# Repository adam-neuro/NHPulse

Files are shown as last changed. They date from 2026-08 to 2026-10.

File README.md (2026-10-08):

# NHPulse

NHPulse is a MATLAB research workflow for individualized non-human-primate
EEG/tES cap design. It extends the ROAST electric-field modeling toolbox with
utilities for synthetic/reviewer examples, subject-specific scalp and implant
registration, capMaker-style layout design, sparse tES targeting, EEG
interleaving, and PLA/TPE STL generation.

The current release is a working research-software alpha. Its thin application
shell opens manifest-backed projects and launches specialized GUIs, while the
reviewer walkthrough remains script-based so every file, setting, and
intermediate product is inspectable.

## Reviewer Quick Start

Open MATLAB from the repository root and run:

```matlab
setNHPulsePath;
P = nhpulseConfigureLocalPaths('profile', 'syntheticMwe');
report = nhpulseCheckDependencies();
```

If the report lists missing dependencies, install those packages before running
the smoke test. A convenient local drop zone is `lib/` inside this repository;
for example, an SPM download may be left as `lib/spm`, `lib/spm12`, or
`lib/spm12-main`. `setNHPulsePath` searches `lib/` for diagnostic dependency
functions rather than requiring exact folder names. You can also point NHPulse
to dependencies installed elsewhere with:

```matlab
P = nhpulseConfigureLocalPaths('profile', 'syntheticMwe', 'useGui', true);
```

or by editing the generated `local.paths.json` file directly. Important fields
include `spmPath`, `iso2meshPath`, `cvxPath`, `getdpExecutable`, and
`gmshExecutable`; see [Configuration](docs/configuration.md) and
[Dependencies And Third-Party Notices](DEPENDENCIES.md) for details.

On macOS, freshly downloaded MATLAB dependencies may have quarantined MEX files.
After configuring paths, clear the quarantine attribute and restart MATLAB:

```matlab
nhpulseClearMacQuarantine({'spm', 'cvx', 'iso2mesh', 'getdp'})
```

If you are only fixing SPM, `nhpulseClearMacQuarantine('spm')` is enough. You
can also pass a direct folder path such as
`nhpulseClearMacQuarantine('/Users/you/Documents/MATLAB/NHPulse/lib/spm12-main')`.
For real ROAST/GetDP solves, also clear the folder containing the GetDP
executable if macOS reports that it cannot be verified.

After the dependency report says the synthetic smoke test is likely runnable,
run:

```matlab
setNHPulsePath;
P = nhpulseConfigureLocalPaths('profile', 'syntheticMwe');
report = nhpulseCheckDependencies();
smokeOut = nhpulseRunSyntheticSmokeTest('force', true, 'showFigures', true);
```

The smoke test records a small manifest-backed run that can immediately be
opened with `nhpulseApp(P.outputRoot)`. Older output folders are shown as
**Unregistered outputs** and can be adopted without moving their files.

Then open [exampleWalkthrough.m](exampleWalkthrough.m) and run the cells in
order. The default preset uses interactive GUI steps and dummy lead fields so a
reviewer can exercise the full cap-manufacturing path without waiting for long
finite-element solves. To run the same walkthrough without interaction:

```matlab
cfg = nhpulseExampleConfig('syntheticFast');
```

To exercise real ROAST/GetDP lead-field generation on the synthetic head, use:

```matlab
cfg = nhpulseExampleConfig('syntheticRoast');
```

At the end of the walkthrough, or after a previously completed run:

```matlab
verification = nhpulseVerifySyntheticWalkthrough();
```

## Documentation

- [Application shell](docs/application.md): project/run selection, workflow
  navigation, artifact status, and specialized GUI launchers.
- [Run manifests and artifact provenance](docs/manifests.md)
- [Stable pipeline services](docs/services.md): explicit, workspace-independent
  stage APIs for scripts and future GUI clients.

- [Installation](docs/installation.md): MATLAB path setup, local paths, and
  third-party dependencies.
- [Synthetic Walkthrough](docs/synthetic_walkthrough.md): the supported public
  example from synthetic anatomy to STL files.
- [Troubleshooting](docs/troubleshooting.md): common setup, macOS quarantine,
  ROAST, GetDP, and output-path failures.
- [User Manual](docs/user_manual.md): conceptual workflow and where the major
  functions fit.
- [API Reference](docs/api_reference.md): public setup, modeling, optimization,
  manufacturing, and quality-control utilities.
- [3D Printing And Fabrication](docs/fabrication.md): tested PLA/TPE printing
  setup, Cura slicing steps, and optional TAZ Pro G-code patching.
- [Configuration](docs/configuration.md): `local.paths.json` and
  `nhpulseExampleConfig` presets.
- [Validation](docs/validation.md): smoke tests, verification, and manual test
  expectations.
- [Example Data](docs/example_data.md): why generated synthetic data are used
  instead of committing real MRI/scan products.
- [Dependencies And Third-Party Notices](DEPENDENCIES.md): MATLAB toolboxes,
  ROAST, SPM, iso2mesh, CVX, GetDP, Gmsh, and macaque tissue priors.
- [Citation](CITATION.md): citations for NHPulse, ROAST, optimization methods,
  and macaque tissue priors.

## What NHPulse Adds

- Synthetic ROAST-ready NHP-like anatomy for reproducible public examples.
- ROAST-compatible wrappers for custom capMaker electrode layouts and optional
  subject-specific tissue/implant handling.
- Scalp, phone-scan, digitizer-trace, fiducial, headpost, chamber, ear, and
  painted exclusion utilities.
- Iterative tES candidate growth with surrogate prediction and UCB-style
  exploration.
- Sparse tES optimization and channel-count sweep utilities.
- EEG layout interleaving that respects tES contacts and manufacturing
  exclusions.
- capMaker manufacturing helpers for electrode holders, rails, recommended
  Velcro attachment loops, legacy chin straps, fit-check scaffolds, STL export,
  and QC/inspection figures.

## Relationship To ROAST

This repository includes and modifies ROAST:

> Huang, Y., Datta, A., Bikson, M., Parra, L.C. Realistic vOlumetric-Approach
> to Simulate Transcranial Electric Stimulation -- ROAST -- a fully automated
> open-source pipeline. Journal of Neural Engineering 16(5), 2019.
> <https://doi.org/10.1088/1741-2552/ab208d>

The upstream ROAST README is preserved at
[docs/ROAST_README.md](docs/ROAST_README.md). Please see
[CITATION.md](CITATION.md) for citation details.

## Caveats

- NHPulse is research software. It is not a medical device and is not validated
  for clinical decision-making.
- Real MRI, phone/LiDAR scans, animal photographs, lead fields, and STL/G-code
  products should remain outside git.
- Full ROAST/GetDP solves can still be slow, even when the synthetic example is
  small. The default walkthrough uses dummy lead fields for reviewer speed.

## License

ROAST is distributed under GPL version 3 or later, with notes in
[LICENSE.md](LICENSE.md) and [docs/ROAST_README.md](docs/ROAST_README.md).
Unless otherwise stated, added NHPulse workflow code in this repository should
be treated as part of the same GPL-licensed research codebase.

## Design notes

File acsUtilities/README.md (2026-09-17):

# ACS Utilities

Small project utilities for keeping machine-specific paths and generated
data products out of the source tree.

## Local Paths

Path resolution is centralized in `acsPaths.m` and `acsSubjectPath.m`.
For a fresh clone, run this from the repository root:

```matlab
setNHPulsePath;
P = nhpulseConfigureLocalPaths('profile', 'syntheticMwe');
```

This creates `local.paths.json` with demo-friendly defaults. To choose local
folders with dialogs, run:

```matlab
P = nhpulseConfigureLocalPaths('profile', 'syntheticMwe', 'useGui', true);
```

`acsPaths` checks, in order:

1. Function name-value overrides.
2. Environment variables such as `ACS_BOX_ROOT`, `ACS_DATA_ROOT`, and
   `ACS_OUTPUT_ROOT`.
3. A local `local.paths.json` file in the repository root or `acsUtilities/`.
4. Common Box locations on Windows and macOS.

`local.paths.json` is ignored by git. You can edit it directly after it is
generated, or use `acsUtilities/local.paths.example.json` as a reference.
The main fields are:

- `outputRoot`: generated files, QC figures, lead fields, and STL products.
- `dataRoot`: optional private source data such as real MRI or scan exports.
- `roastWorkRoot`: scratch/work products from long ROAST jobs.
- `spmPath`, `iso2meshPath`, `cvxPath`, `niftiPath`: optional external
  MATLAB dependency folders.
- `getdpExecutable`, `gmshExecutable`: optional solver/viewer executable paths.
- `inpolyhedronPath`: mesh voxelization helper; the public repo includes this
  under `acsUtilities/inpolyhedron.m`.

Subject aliases live in the per-subject `aliases` array in
`local.paths.json`. Use a canonical subject key that is a valid MATLAB
field name, such as `M2107`, then list scanner IDs and lab nicknames as
aliases:

```json
"subjects": {
  "M2107": {
    "aliases": ["2107", "21-07", "M21-07", "reeses"],
    "mprageInitial": "..."
  }
}
```

## Generated Products

Generated images, meshes, ROAST results, template products, and cap caches
should be written under `acsPaths().outputRoot` or another explicitly
configured external folder. The repository root `.gitignore` excludes the
default `outputs/` folder and common large neuroimaging/modeling products.

## DICOM Anatomy Import

Use `acsImportDicomAnatomy` as the first individual-subject preprocessing
step. It converts a DICOM series into a canonical NIfTI plus an import
report, without attempting segmentation or registration.

Example:

```matlab
out = acsImportDicomAnatomy('M2107', ...
    'verbose', true, ...
    'showFigures', true, ...
    'saveFigures', true);
```

## Raw Volume Orientation Labeling

Use `acsLabelVolumeOrientation` when scanner/header orientation may be
wrong and you need to label the raw voxel-array dimensions directly. The
viewer does not use NIfTI affine/header orientation to reorient the data.
It displays three linked raw slice views through one voxel. Use the sliders
to move through dimensions 1-3, or click a slice to update the other two
dimensions, then enter a three-character code such as `ras`.

The same viewer can also be used as a target voxel picker. `out.currentVoxel`
always contains the final crosshair position. For multiple targets, pass
`'voxelSelectionMode','multiple'`, click through the volume, and press `A` or
the Add voxel button for each target. The selected target list is returned in
`out.selectedVoxels`; if no explicit target was added, `selectedVoxels` falls
back to `currentVoxel`.

Example:

```matlab
out = acsLabelVolumeOrientation( ...
    'C:/path/to/M2107_T1.nii', ...
    'orientationCode', 'ask', ...
    'saveFigures', true);
```

To inspect without entering a code:

```matlab
out = acsLabelVolumeOrientation( ...
    'C:/path/to/M2107_T1.nii', ...
    'orientationCode', '');
```

For later scripted calls, pass a known code directly:

```matlab
out = acsLabelVolumeOrientation( ...
    'C:/path/to/M2107_T1.nii', ...
    'orientationCode', 'ras', ...
    'showFigures', false);
```

## Macaque TPM Segmentation

Use `acsSegmentAnatomyWithTpm` after DICOM import to run SPM unified
segmentation with a six-channel macaque TPM. By default it looks for
`defaultMonkeyTpm.nii` under `acsPaths().dataRoot/MRIs/atlasfiles`, with a
temporary fallback to the historical `myTpm.nii` name.

For real rhesus macaque workflows, the default `templateMaker` atlas-prior
filenames (`gm_priors_ohsu+uw.nii`, `wm_priors_ohsu+uw.nii`, and
`csf_priors_ohsu+uw.nii`) correspond to the 112RM-SL rhesus macaque atlas
priors described by McLaren et al. (2009). The generated six-channel
ROAST/SPM-style TPM is a local derived product and should stay outside git.
See [../CITATION.md](../CITATION.md) and [../DEPENDENCIES.md](../DEPENDENCIES.md)
for citation and download notes.

The TPM channel order is assumed to match ROAST/SPM:

1. gray matter
2. white matter
3. CSF
4. bone
5. skin/scalp
6. air/background

Example:

```matlab
out = acsSegmentAnatomyWithTpm('M2107', ...
    'verbose', true, ...
    'showFigures', true, ...
    'saveFigures', true);
```

SPM's affine regularization is exposed as `affineRegularization`. The
default is `mni`, matching SPM/ROAST defaults. For comparison runs, use
`segmentationTag` so each run is written to a separate ignored output
subfolder:

```matlab
out = acsSegmentAnatomyWithTpm('M2107', ...
    'segmentationTag', 'affreg_subj', ...
    'affineRegularization', 'subj', ...
    'forceCopyInput', true, ...
    'forceSegmentation', true, ...
    'showFigures', true, ...
    'saveFigures', true);
```

Useful `affineRegularization` values are `mni`, `subj`, `none`, and `''`.
Here `none` still performs affine registration but disables affine
regularization; `''` skips the initial affine registration.

The segmentation wrapper does not trust header orientation. It uses raw
voxel orientation codes, writes RAS-oriented working copies of the T1 and
TPM into the ignored segmentation folder, and passes those derived files to
SPM. The current defaults are `t1Orientation='sar'` for M2107 and
`tpmOrientation='ras'` for `defaultMonkeyTpm.nii`:

```matlab
out = acsSegmentAnatomyWithTpm('M2107', ...
    'segmentationTag', 'ras_inputs', ...
    't1Orientation', 'sar', ...
    'tpmOrientation', 'ras', ...
    'forceCopyInput', true, ...
    'forceSegmentation', true, ...
    'showFigures', true, ...
    'saveFigures', true);
```

Use `ask` for either source to launch `acsLabelVolumeOrientation` from the
segmentation workflow:

```matlab
out = acsSegmentAnatomyWithTpm('M2107', ...
    't1Orientation', 'ask', ...
    'tpmOrientation', 'ask', ...
    'tpmOrientationVolume', 1, ...
    'showFigures', true);
```

By default the wrapper also creates subject-derived head/interior masks from
the RAS T1 and passes the head mask to SPM as an explicit mask. These masks
are written under the ignored segmentation output folder:

```matlab
out = acsSegmentAnatomyWithTpm('M2107', ...
    'segmentationTag', 'head_masked', ...
    'spmMaskMode', 'head', ...
    'forceSegmentation', true, ...
    'showFigures', true, ...
    'saveFigures', true);
```

Useful `spmMaskMode` values are `none`, `head`, `innerHead`, and
`brainSearch`. `head` is the conservative default and mainly suppresses
outside-head speckles. `innerHead` and `brainSearch` are tighter masks for
debugging or later brain-focused registration experiments. You can provide a
custom mask directly with `subjectMaskFile`.

Standalone mask QC is also available:

```matlab
out = acsMakeSubjectMasks( ...
    'C:/path/to/M2107_T1_RAS_fromSAR.nii', ...
    'showFigures', true, ...
    'saveFigures', true);
```

SPM's explicit mask constrains the segmentation sampling/classification
stage, but it does not solve the harder problem of registering a
brain-only TPM to a whole-head T1 by itself. For that we will likely add a
separate brain-focused registration/masking step.

When figures are enabled, the wrapper saves two soft-probability contour
figures plus a maximum-probability tissue figure. The latter displays the
winner-take-all tissue identity at each displayed voxel, which is useful for
distinguishing true tissue-label errors from overlapping probability
contours:

```matlab
out = acsSegmentAnatomyWithTpm('M2107', ...
    'segmentationTag', 'map_qc', ...
    'forceSegmentation', true, ...
    'showFigures', true, ...
    'saveFigures', true, ...
    'qcMaxTissueMinProbability', 0.35);
```

Because T1 anatomy does not reliably distinguish skull from other low-signal
structures, the wrapper applies a subject-specific cranium-shell correction
to the bone probability map by default. It builds a fuzzy shell from the
merged brain probabilities, boosts bone inside that shell, suppresses bone
outside it, and renormalizes all six tissue maps. The original SPM `c1..c6`
files are left intact; corrected files are written with a `shellPrior` suffix
and used for QC/reporting.

```matlab
out = acsSegmentAnatomyWithTpm('M2107', ...
    'segmentationTag', 'shell_bone', ...
    'forceSegmentation', true, ...
    'showFigures', true, ...
    'saveFigures', true);
```

Useful bone options:

```matlab
'boneMode', 'shellPrior'          % default; strong but not deterministic
'boneMode', 'spm'                 % use raw SPM c4
'boneMode', 'shellOnly'           % deterministic shell-style replacement
'boneShellDilateMm', 5
'boneShellFloor', 0.05
'boneShellBoost', 8
'boneShellAdd', 0.20
```

The wrapper also writes a ROAST-ready hard tissue label volume by default,
using the active probability maps after any bone correction. Labels follow
ROAST order: `0 background`, `1 white`, `2 gray`, `3 CSF`, `4 bone`,
`5 skin`, `6 air`. Low-confidence voxels inside the configured head mask are
assigned to air; voxels outside the head mask remain background. The label
volume is written directly to ROAST's expected mask filename for the active T1,
avoiding an extra adapter copy:
`<activeT1>_T1orT2_SPM_masks.nii`. A small `<activeT1>_T1orT2_seg8.mat`
metadata alias is also created so ROAST can skip its own SPM segmentation.

```matlab
out = acsSegmentAnatomyWithTpm('M2107', ...
    'segmentationTag', 'roast_labels', ...
    'boneMode', 'shellOnly', ...
    'forceRoastLabels', true, ...
    'showFigures', true, ...
    'saveFigures', true);
```

Useful label options:

```matlab
'makeRoastLabels', true
'roastLabelMinProbability', 0.35
'roastLabelConstraintMask', 'head'
```

The wrapper reports these files under `out.roastReady`. For an initial ROAST
smoke test, pass `out.roastReady.t1File` to `roast` and keep resampling off so
the filenames continue to match:

```matlab
recipe = {'Fp1', 1, 'P4', -1};
roast(out.roastReady.t1File, recipe, 'resampling', 'off');
```

### capMaker Custom Layouts

Use `acsMakeRoastCapMakerLayout` to generate a ROAST custom electrode layout
from capMaker's simple automatic target placement. By default the utility
uses capMaker's outer scalp mesh for target selection, transforms those
targets into the ROAST voxel frame, snaps them to the ROAST outer-head
surface, and writes `<activeT1>_customLocations` next to the ROAST-ready T1.
The written coordinates are in the voxel coordinate frame ROAST expects when
resampling is off. By default the capMaker surface is now built from the same
ROAST-ready RAS T1 that is passed to ROAST, not from the original DICOM folder.
That keeps the coordinate transform deterministic: the exporter inverts the
capMaker print translation and crop-plane alignment rotation, then lands
directly back in the ROAST RAS voxel lattice.

The capMaker plots are in its print frame, where `Z = 0` is the 3D printer
bed; the ROAST QC panel is in ROAST's scaled image/mesh frame, so the numeric
origins are not expected to match. If you explicitly pass `dicomDir`, the
legacy DICOM route is used and `capMakerVoxelOrientation` can still be
overridden for debugging. Large snap distances trigger a warning because they
usually indicate a transform mismatch.

To choose the capMaker crop plane interactively, use
`'cropPlaneMode', 'select'`. Drag in the 3D view to rotate the camera, scroll
to move the plane, Ctrl-click or Command-click to redirect the crop axis, and
Alt-click or Option-click to move the plane through a picked scalp point.
Press `x`, `y`, or `z` to reset the camera to a canonical view along that
world axis. The GUI renders a decimated display mesh by default while retaining
the full-resolution surface for plane placement and picking.
The accepted plane is saved as a small MAT file and a human-readable JSON
file under the subject's ignored `capMaker` work folder. It is separate from
the cached scalp mesh so it can be inspected and reused reproducibly.

```matlab
layout = acsMakeRoastCapMakerLayout(out, ...
    'surfaceSource', 'capMaker', ...
    'cropPlaneMode', 'select', ...
    'forceLayout', true, ...
    'showFigures', true, ...
    'saveFigures', true, ...
    'verbose', true);

% For a later non-interactive run that requires the saved plane:
layout = acsMakeRoastCapMakerLayout(out, ...
    'surfaceSource', 'capMaker', ...
    'cropPlaneMode', 'reuse', ...
    'forceLayout', true, ...
    'showFigures', true);
```

The default `cropPlaneMode='auto'` reuses a saved crop plane when one exists
and otherwise uses capMaker defaults. Use `'default'` to ignore any saved
selection. If a saved plane changes, the wrapper recomputes the scalp mesh
instead of silently loading a stale cache.
Use `cropPlaneMode='autoSelect'` when you want the wrapper to reuse a saved
crop plane if one exists, but open the crop-plane selector and save a new plane
when none has been defined yet. `forceLayout` controls whether the generated
`customLocations` file is overwritten; the older name `force` is still accepted
as an alias.

If camera movement is still sluggish on a particular machine, lower the
display-only triangle budget without affecting the saved plane geometry:

```matlab
skinOpts = struct('cropGuiOptions', struct('displayMaxFaces', 5000));
layout = acsMakeRoastCapMakerLayout(out, ...
    'cropPlaneMode', 'select', ...
    'skinMeshOptions', skinOpts);
```

```matlab
layout = acsMakeRoastCapMakerLayout(out, ...
    'nElectrodes', 8, ...
    'surfaceSource', 'capMaker', ...
    'forceLayout', true, ...
    'showFigures', true, ...
    'saveFigures', true);

recipe = {layout.names{1}, 1, layout.names{2}, -1};
roast(out.roastReady.t1File, recipe, ...
    'resampling', 'off', ...
    'simulationTag', 'capMakerSmoke');
```

The established electrode-placement behavior remains available as
`placementMode='footprintCvt'` and is still the default. It fits a 2-D
footprint, distributes electrodes in that footprint, and projects them down
onto the cap. To test mesh-native placement, pass
`placementMode='surfaceGeodesic'` through `targetOptions`:

```matlab
targetOpts = struct( ...
    'placementMode', 'surfaceGeodesic', ...
    'edgeMarginMM', 10, ...
    'vizSurfaceGeodesic', true);

layout = acsMakeRoastCapMakerLayout(out, ...
    'surfaceSource', 'capMaker', ...
    'targetOptions', targetOpts, ...
    'force', true, ...
    'showFigures', true, ...
    'saveFigures', true, ...
    'verbose', true);
```

The surface-geodesic mode detects the fabricated printer-bed patch, excludes
its vertices, excludes an additional geodesic margin from its crop rim, and
computes electrode spacing only across the remaining scalp graph. Steep scalp
surfaces remain eligible by default. Bilateral pairs also treat the midline as
a special edge: paired targets must remain at least `midlineMarginMM` lateral
X distance from `symmetryPlaneX`. This defaults to `edgeMarginMM`; odd layouts may still
include one dedicated midline target. Set `visibleFromAbove=true` as an
optional extra safeguard if a particular cap should retain the legacy
top-visible constraint. Mesh-specific ear exclusion spheres and the headpost
disk are applied before sampling. Additional implanted-material avoidance
regions can be specified in capMaker print coordinates:

```matlab
targetOpts.exclusionCenters = [12 -8 34; -12 -8 34];
targetOpts.exclusionRadiusMM = 8;
```

For subject-specific ear avoidance, `acsMakeRoastCapMakerLayout` now uses the
current capMaker scalp mesh to load reusable left/right exclusion spheres, or
opens the selector when no saved file exists. The first proposal places the
spheres at extreme left/right points near the caudal lower third of the mesh,
with an initial diameter equal to one quarter of the left-right scalp range.
In the GUI, Shift-click the scalp to move the active sphere center near the
clicked point, use arrow keys plus `u`/`d` to nudge the center in X/Y/Z, and
use `i`/`o` or the mouse wheel to shrink/grow the radius:

```matlab
layout = acsMakeRoastCapMakerLayout(out, ...
    'surfaceSource', 'capMaker', ...
    'earExclusionMode', 'auto', ...
    'showFigures', true, ...
    'saveFigures', true);
```

`earExclusionMode='auto'` opens the editor only when the mesh-specific
ear-exclusion file does not exist, then reuses that file quietly on later runs.
Use `earExclusionMode='always'` to revise saved spheres, or
`earExclusionMode='never'` to avoid opening the editor and use the saved file
or automatic proposal quietly. The low-level selector
`acsSelectEarExclusionSpheres` remains available when you want to inspect or
edit the saved file directly.

`surfaceGeodesic` requires the triangulated capMaker scalp surface. The
point-cloud-only debugging route `surfaceSource='roastLabels'` continues to
support `footprintCvt`.

For EEG coverage layouts, use `placementMode='surfaceVoronoi'`. This mode
builds compact geodesic Voronoi cells over the anatomical scalp coverage
surface above the printer bed, while applying edge, ear, headpost, tES, and
other exclusion rules only when snapping each cell center to a legal electrode
placement vertex:

```matlab
eegTargetOpts = targetOpts;
eegTargetOpts.placementMode = 'surfaceVoronoi';
eegTargetOpts.preferSymmetry = false;
eegTargetOpts.midlineMarginMM = 0;
eegTargetOpts.voronoiIterations = 10;
eegTargetOpts.voronoiSnapMode = 'spacingAware';
eegTargetOpts.voronoiSpacingWeight = 4;
eegTargetOpts.voronoiMinSpacingFraction = 0.75;
eegTargetOpts.vizSurfaceVoronoi = true;
```

The Voronoi QC figure shows colored coverage cells, legal placement vertices,
final electrodes, per-cell area balance, and nearest-neighbor geodesic spacing.
Set `voronoiSnapMode='centroid'` to recover the older centroid-only snapping
behavior. Switch back to
`placementMode='surfaceGeodesic'` to recover the earlier greedy farthest-point
sampler.

For debugging, set `'surfaceSource', 'roastLabels'` to place electrodes from
the filled ROAST label surface instead of the capMaker scalp mesh.

### capMaker Lead Fields

After validating a capMaker layout with a small forward simulation, generate
a reusable ROAST lead field over the custom candidate positions. The ACS
wrapper defaults to capMaker candidates. Its final candidate is used as the
mathematical reference unless another candidate is selected explicitly:

```matlab
lf = acsGenerateRoastLeadField(layout, ...
    'simulationTag', 'M2107_capMakerGeo_lf8', ...
    'resampling', 'off');
```

This calls ROAST's existing lead-field solver path. It places and meshes all
candidate electrodes once, then solves one unit-current basis field for each
non-reference candidate against the reference. All custom candidate contacts
remain in the modeled domain during each solve; passive contacts receive zero
current. The resulting `A_all` matrix can be linearly combined to evaluate
new montages without another FEM solve.

The wrapper also preserves the tiny custom-location text file under the
lead-field tag. ROAST still receives its expected mutable
`<T1 stem>_customLocations` file, while older and newer candidate layouts can
be traced back to the coordinates that generated each lead field.

For a strict superposition check, ask the validator to run one direct GetDP
solve on the existing lead-field mesh. The inactive candidates deliberately
receive zero current so that the direct and reconstructed fields represent
the same physical model. The temporary direct field file is removed after QC
by default:

```matlab
check = acsValidateRoastLeadField(layout.t1File, ...
    lf.simulationTag, ...
    lf.validationRecipe, ...
    'showFigures', true, ...
    'saveFigures', true);
```

For local development when the real ROAST/GetDP lead-field solve is too slow,
use `acsGenerateDummyRoastLeadField`. It writes the `A_all`,
`*_roastOptions.mat`, mesh MAT, custom-location snapshot, and request report
that the ACS optimizer expects, but marks every report and options struct with
`dummy=true` and uses a `DUMMY_...` simulation tag. These fields are smooth
synthetic patterns for exercising downstream code only.

```matlab
lf = acsGenerateDummyRoastLeadField(layout, ...
    'simulationTag', 'DUMMY_M2107_capMakerGeo_lf16', ...
    'force', true);
```

Skip `acsValidateRoastLeadField` for dummy outputs; that validation checks
superposition against a direct GetDP solve and requires real ROAST mesh products.

The original ROAST 10-10 lead-field behavior remains available explicitly:

```matlab
lfLegacy = acsGenerateRoastLeadField(layout.t1File, ...
    'candidateMode', 'legacy1010', ...
    'simulationTag', 'legacy1010LeadField');
```

### Sparse capMaker Targeting

Choose a sparse montage from the capMaker candidates without any additional
FEM solves. Provide the target in the voxel coordinates of the modeled RAS T1
and provide an explicit desired field direction. Using explicit subject-space
inputs avoids the human-template assumptions in ROAST's MNI and radial
defaults:

```matlab
% Use the linked-slice viewer to choose a target in the modeled RAS T1.
% Click the desired location(s), press A/Add voxel for each one, then press
% Enter at the orientation prompt.
pick = acsLabelVolumeOrientation(layout.t1File, ...
    'orientationCode', 'ask', ...
    'voxelSelectionMode', 'multiple', ...
    'allowSkip', true);
targetVoxel = pick.selectedVoxels;

sparse = acsOptimizeSparseRoastLeadField(layout.t1File, ...
    lf.simulationTag, ...
    targetVoxel, ...
    'orientation', [0 0 1], ...
    'targetRadiusMm', 2, ...
    'activeElectrodeCount', 4, ...
    'targetingTag', 'smokeTarget01', ...
    'showFigures', true, ...
    'saveFigures', true);
```

The utility defaults to a ROAST-style weighted least-squares focal objective
(`optType='wls-l1per'`). It asks for a desired field at the target, penalizes
field elsewhere in the brain, then refines the relaxed solution down to the
requested number of active contacts. The default total injected current is
2 mA and the corresponding four-electrode bound is 1 mA per electrode.

Two tuning knobs matter most:

```matlab
'desiredIntensityVm', 1   % lower this if every selected contact rails
'focalityK', 0.02         % lower = more off-target penalty; higher = more target intensity
```

The earlier maximum-directional behavior remains available as
`optType='max-l1per'`. It is useful as a ceiling check, but it is expected to
drive contacts to their current limits because it does not penalize off-target
field.

To cross-check the scalable solution during development, explicitly request
exhaustive enumeration. With eight candidates, this searches only
`nchoosek(8,4) = 70` subsets:

```matlab
sparseExactCheck = acsOptimizeSparseRoastLeadField(layout.t1File, ...
    lf.simulationTag, ...
    targetVoxel, ...
    'orientation', [0 0 1], ...
    'optType', 'max-l1per', ...
    'activeElectrodeCount', 4, ...
    'searchMode', 'exhaustiveCvx', ...
    'targetingTag', 'smokeTarget01_exhaustive');
```

The exhaustive mode has a safety limit because it is intended for small
development sets, not the eventual 128-channel search.

Visualize the reconstructed field immediately from the lead-field sum,
without another mesh or GetDP solve:

```matlab
fieldQc = acsVisualizeSparseRoastLeadField(sparse, ...
    'showFigures', true, ...
    'saveFigures', true);
```

The viewer colors the gray-matter surface by electric-field magnitude, marks
the selected electrodes and target, and shows target-centered sagittal,
coronal, and axial mesh cuts.

### Incremental 16-candidate Test

Before replacing the current eight-contact layout, snapshot its location
file using the updated wrapper without rerunning ROAST:

```matlab
lf8Archive = acsGenerateRoastLeadField(layout, ...
    'simulationTag', 'M2107_capMakerGeo_lf8', ...
    'resampling', 'off', ...
    'execute', false);
```

Then create and inspect a denser capMaker layout. Reuse the saved crop plane
and scalp mesh:

```matlab
targetOpts16 = struct( ...
    'placementMode', 'surfaceGeodesic', ...
    'edgeMarginMM', 10, ...
    'midlineMarginMM', 10, ...
    'vizSurfaceGeodesic', true);

layout16 = acsMakeRoastCapMakerLayout(out, ...
    'nElectrodes', 16, ...
    'surfaceSource', 'capMaker', ...
    'targetOptions', targetOpts16, ...
    'force', true, ...
    'showFigures', true, ...
    'saveFigures', true, ...
    'verbose', true);
```

After the candidate placement QC looks reasonable, generate the denser lead
field. This is the expensive step: 16 candidates require 15 basis solves.

```matlab
lf16 = acsGenerateRoastLeadField(layout16, ...
    'simulationTag', 'M2107_capMakerGeo_lf16', ...
    'resampling', 'off');
```

Select eight contacts with the scalable global solve and visualize the
reconstructed field:

```matlab
sparse16 = acsOptimizeSparseRoastLeadField(layout16.t1File, ...
    lf16.simulationTag, ...
    targetVoxel, ...
    'orientation', [0 0 1], ...
    'activeElectrodeCount', 8, ...
    'optType', 'wls-l1per', ...
    'desiredIntensityVm', 0.5, ...
    'focalityK', 0.02, ...
    'targetingTag', 'smokeTarget16choose8', ...
    'showFigures', true, ...
    'saveFigures', true);

fieldQc16 = acsVisualizeSparseRoastLeadField(sparse16, ...
    'showFigures', true, ...
    'saveFigures', true);
```

If the selected currents all sit at `+/- maxCurrentPerElectrodeMa`, the
desired field is probably too high for the requested focality. Try lowering
`desiredIntensityVm`. If the target is hit but the map is too broad, try a
smaller `focalityK`; if the solution is too weak at the target, try a larger
`focalityK`.

### Surrogate-Guided Candidate Growth

Use `acsProposeRoastCandidateGrowth` to grow a candidate set before spending
time on another ROAST lead-field run. The utility samples legal virtual
locations on the capMaker scalp mesh, uses Gaussian RBF regression to predict
reduced lead-field features from the existing real leadfield, and greedily
selects points expected to reduce the current WLS residual. The current
default acquisition mode is upper-confidence-bound (`acquisitionMode='ucb'`),
which balances predicted utility with distance/uncertainty relative to the
already sampled electrode locations.

The virtual pool is drawn from the eligible vertices on the existing capMaker
scalp mesh. If fewer vertices are available than `poolSize`, the utility warns
and scores all available vertices. By default it also enforces a 12 mm
center-to-center spacing: 10 mm for the BioSemi-style plastic housing
footprint plus 2 mm clearance. For denser candidate searches, recompute the
capMaker scalp mesh with less decimation, then regenerate the base layout and
leadfield from that mesh.

First inspect a proposal without overwriting the active ROAST
`customLocations` file:

```matlab
grow = acsProposeRoastCandidateGrowth(layout16, sparse16, ...
    'nNew', 8, ...
    'poolSize', 128, ...
    'kernelSigmaMm', 'auto', ...
    'proposalTag', 'grow16to24_target01', ...
    'showFigures', true, ...
    'saveFigures', true);
```

If the QC looks sensible, write an expanded capMaker/ROAST layout using the
exact proposed print-frame coordinates:

```matlab
grow = acsProposeRoastCandidateGrowth(layout16, sparse16, ...
    'nNew', 8, ...
    'poolSize', 128, ...
    'proposalTag', 'grow16to24_target01', ...
    'makeLayout', true, ...
    'forceLayout', true, ...
    'showFigures', true, ...
    'saveFigures', true);

preflight24 = acsVisualizeRoastElectrodeLayout(grow.expandedLayout, ...
    'electrodeModel', 'biosemiPin', ...
    'showFigures', true, ...
    'saveFigures', true);

lf24 = acsGenerateRoastLeadField(grow.expandedLayout, ...
    'simulationTag', 'M2107_capMakerGeo_lf24_surrogate01', ...
    'electrodeModel', 'biosemiPin', ...
    'resampling', 'off');
```

For faster iterative growth, write a surrogate-expanded leadfield product
instead of running ROAST on every intermediate candidate set:

```matlab
lf24Approx = acsGenerateApproximateExpandedRoastLeadField( ...
    layout16, lf16, grow.expandedLayout, ...
    'simulationTag', 'M2107_capMakerGeo_lf24_approxGrow01', ...
    'referenceElectrode', lf16.referenceElectrode);
```

This copies existing `A_all` columns and appends Gaussian RBF-predicted
columns for newly proposed contacts while keeping the same reference electrode.
Downstream sparse optimization can read the resulting ROAST-style files, but
the product is marked approximate in `*_roastOptions.mat` and is intentionally
ignored by exact lead-field cache matching. Because adding contacts changes
the ROAST electrode domain and mesh, do not treat surrogate-expanded columns
as final physics; run a fresh exact leadfield on the final candidate set.

`electrodeModel='biosemiPin'` approximates the conductive Ag/AgCl pin as a
ROAST disc with radius 1 mm and height 5 mm, places its lower end 0.5 mm above
the scalp, and surrounds it with a 2.5 mm radius by 2.5 mm high gel pool.
ROAST does not model the surrounding plastic housing as conductive material;
the housing footprint is handled by the candidate-spacing constraints above. Use
`electrodeModel='roastDefault'` to recover ROAST's default 6 mm radius disc.
`acsVisualizeRoastElectrodeLayout` is a preflight visualization/check that
reports ROAST-domain collision risk, including gel-pool overlap, and
housing-risk nearest-neighbor pairs before ROAST voxelizes the electrodes.

After sparse tES targeting, use `acsAssembleTesEegCapMakerLayout` to build a
combined cap layout for manufacturing:

```matlab
eegTargetOpts = targetOpts;
eegTargetOpts.placementMode = 'surfaceVoronoi';
eegTargetOpts.preferSymmetry = false;
eegTargetOpts.midlineMarginMM = 0;

combinedLayout = acsAssembleTesEegCapMakerLayout(grow.expandedLayout, sparse, ...
    'nTes', 8, ...
    'nEeg', 8, ...
    'eegPreferSymmetry', false, ...
    'eegMidlineMarginMM', 0, ...
    'eegExclusionRadiusMm', 12, ...
    'eegTargetOptions', eegTargetOpts, ...
    'forceLayout', true, ...
    'showFigures', true, ...
    'saveFigures', true);
```

The EEG sites are placed with the same capMaker surface rules while treating
the selected tES sites as exclusion centers. EEG symmetry is off by default in
this assembly step to improve coverage around fixed tES sites. By default,
asymmetric EEG placement also removes the midline buffer while preserving the
base cap edge margin and ear/headpost exclusions. Pass `'eegPreferSymmetry',
true` to restore bilateral pairing. The combined layout records `siteRoles`,
`tesCurrentsMa`, `eegTargetOptions`, and the source tES electrode names.
`forceLayout` controls whether the generated EEG-only and combined layout files
are overwritten; the older name `force` is still accepted as an alias.

To predict what the passive EEG contacts would measure during a selected tES
montage, run a direct ROAST solve from the combined layout. The utility maps
recipe names from the sparse candidate layout onto the combined tES names,
adds all EEG contacts as zero-current passive electrodes, and samples nodal
voltage over each EEG electrode domain:

```matlab
tesRecipe = sparse.recipe;

eegPrediction = acsPredictEegVoltagesFromTes(combinedLayout, tesRecipe, ...
    'simulationTag', 'M2107_tes8_eeg8_voltageCheck', ...
    'electrodeModel', 'biosemiPin', ...
    'resampling', 'off', ...
    'sampleDomain', 'electrode', ...
    'referenceMode', 'meanEeg', ...
    'showFigures', true, ...
    'saveFigures', true);

eegPrediction.eegTable
```

The default reference is the mean of the sampled EEG channels. Use
`referenceMode='none'` for raw arbitrary-reference GetDP potentials, or pass an
EEG channel name to reference all channels to that contact.

Visualize the sampled EEG voltage topography on the capMaker scalp mesh:

```matlab
eegTopo = acsVisualizeEegVoltageTopography(eegPrediction, combinedLayout, ...
    'valueMode', 'referencedMicroV', ...
    'interpolation', 'rbf', ...
    'showTes', true, ...
    'showFigures', true, ...
    'saveFigures', true);
```

The topography uses a smooth Gaussian interpolation between sparse EEG
channels, so it is a visualization aid rather than a new forward model. Use
`interpolation='nearest'` to inspect channel domains without smoothing, or set
`rbfSigmaMM` to tune the smoothing width.

## Saved Digitizer Traces

The public release does not include a live hardware acquisition GUI. Users can
collect 3D points with their preferred digitizer workflow, then bring saved
fiducial points, scalp traces, implant traces, or electrode-QC points into
NHPulse for registration and visualization.

Several historical utility names still include `Polhemus`; in the public
release, those functions operate on saved point-set files or structs and do
not require Polhemus hardware or MATLAB Instrument Control Toolbox. Point-set
files should provide labels plus coordinates in millimeters, and optional
trace/object groupings for scalp or implant loops.

Use `acsMonkeyLandmarkBullpen` to get the shared macaque landmark list for
model-fiducial selection and external digitizer prompts:

```matlab
landmarkLabels = acsMonkeyLandmarkBullpen('labels');
```

Use `acsRegisterPolhemusFiducials` to align saved digitizer points to MRI,
ROAST, or capMaker coordinates once the corresponding model-space fiducials
have been identified:

```matlab
modelFiducials = acsSelectModelFiducials(combinedLayout, ...
    'fiducialLabels', {'Nas', 'Lpa', 'Rpa'}, ...
    'meshStage', 'fullHead', ...
    'editMode', 'auto', ...
    'showFigures', true, ...
    'saveFigures', true);

registration = acsRegisterPolhemusFiducials( ...
    'C:/path/to/digitizer_session.mat', ...
    modelFiducials, ...
    'modelUnits', 'mm', ...
    'transformType', 'rigid');
```

`acsSelectModelFiducials` defaults to the uncropped full-head fiducial mesh
because `Nas`, `Lpa`, and `Rpa` are usually cropped out of the manufacturing
cap mesh. The selected points are still saved in capMaker print-frame
millimeters, using the same print transform as the cropped cap mesh.
Shift-click the head mesh to place the active fiducial; drag rotates the view.
The registration output transforms every saved digitizer point, not just
`Nas`/`Lpa`/`Rpa`:

For an all-landmark assessment, use the same bullpen labels when selecting
model fiducials and when registering/visualizing the digitizer session:

```matlab
landmarkLabels = acsMonkeyLandmarkBullpen('labels');

modelLandmarks = acsSelectModelFiducials(combinedLayout, ...
    'fiducialLabels', landmarkLabels, ...
    'meshStage', 'fullHead', ...
    'editMode', 'always', ...
    'showFigures', true);

traceQc = acsVisualizePolhemusTraceOnHead( ...
    'C:/path/to/landmarkAssessmentSession.mat', ...
    modelLandmarks, ...
    'fiducialLabels', landmarkLabels, ...
    'showFigures', true);
```

Use `meshStage='cap'` only for non-anatomical points that are known to be on
the cropped cap surface. If a full-head fiducial mesh is missing from an older
cache, rerun the capMaker layout step so the cache is rebuilt with
`TRfiducialHead`.

```matlab
registration.transformedSourcePointsMm   % capMaker print-frame points
registration.registeredObjects           % transformed implant traces
```

For a quick QC overlay of saved scalp or implant traces on the full-head
capMaker mesh, use:

```matlab
traceQc = acsVisualizePolhemusTraceOnHead( ...
    'C:/path/to/headpostTraceSession.mat', ...
    modelFiducials, ...
    'fiducialLabels', {'Nas', 'Lpa', 'Rpa'}, ...
    'showFigures', true, ...
    'saveFigures', true);
```

If the digitizer report contains named `objects`, those are drawn separately.
Otherwise all non-fiducial points are treated as one ordered trace. The output
reports nearest-head-mesh distances for a first-pass registration sanity
check.

The transform is row-vector based:

```matlab
pointsModelMm = pointsDigitizerMm * registration.rotation + ...
    registration.translationMm;
```

For the ROAST/capMaker integration path, convert those registered capMaker
print-frame points back into the input MRI frame with the saved skin-mesh
metadata:

```matlab
polhemusMri = acsCapMakerPrintToMriFrame(registration, modelFiducials);

polhemusMri.mriWorldCoordinatesMm
polhemusMri.mriVoxel1
polhemusMri.objects                 % traced implants converted to MRI frame
```

For NIfTI-driven capMaker runs, `mriWorldCoordinatesMm` is the zero-based MRI
millimeter lattice used by the capMaker skin-mesh preprocessing, and
`mriVoxel1` gives MATLAB/SPM-style one-based voxel coordinates.

For cross-session cap QC alignment, pass the repeatable headpost/chair labels
as the registration fiducials:

```matlab
sessionToSession = acsRegisterPolhemusFiducials( ...
    'C:/path/to/session_today.mat', ...
    'C:/path/to/session_reference.mat', ...
    'fiducialLabels', {'headpost1', 'headpost2', ...
        'rightChairPoint', 'leftChairPoint', 'topChairPoint'});
```

Once the combined layout has been accepted, plan reinforced Velcro attachment
loops and build capMaker manufacturing STLs directly from those final
print-frame electrode coordinates:

```matlab
velcroPlan = acsPlanVelcroAnchors(combinedLayout, ...
    'earExclusionFile', activeEarExclusionFile, ...
    'outputFile', fullfile(pwd, 'outputs', 'debug', ...
        'M2107_tes8_eeg8_velcroAnchors.mat'), ...
    'editMode', 'always', ...
    'showFigures', true);

manufacturingPreflight = acsBuildCapMakerManufacturingStl(combinedLayout, ...
    'manufacturingTag', 'M2107_tes8_eeg8_cap_v01', ...
    'earExclusionMode', 'auto', ...
    'railEarExclusionMode', 'projectedSpheres', ...
    'strapMode', 'none', ...
    'velcroAnchorMode', 'file', ...
    'velcroAnchorFile', velcroPlan.outputFile, ...
    'holderSupportMode', 'nearestRail', ...
    'holderSupportCount', 2, ...
    'holderSupportMinAngleDeg', 90, ...
    'holderBridgeMode', 'auto', ...
    'manufacturingSurfaceMaxFaces', 5000, ...
    'railSurfaceMaxFaces', 5000, ...
    'preflightOnly', true, ...
    'showFigures', true, ...
    'saveFigures', true, ...
    'force', true);

manufacturing = acsBuildCapMakerManufacturingStl(combinedLayout, ...
    'manufacturingTag', 'M2107_tes8_eeg8_cap_v01', ...
    'earExclusionMode', 'auto', ...
    'railEarExclusionMode', 'projectedSpheres', ...
    'strapMode', 'none', ...
    'velcroAnchorMode', 'file', ...
    'velcroAnchorFile', velcroPlan.outputFile, ...
    'holderSupportMode', 'nearestRail', ...
    'holderSupportCount', 2, ...
    'holderSupportMinAngleDeg', 90, ...
    'holderBridgeMode', 'auto', ...
    'manufacturingSurfaceMaxFaces', 5000, ...
    'railSurfaceMaxFaces', 5000, ...
    'voxelSizeMm', 0.75, ...
    'showFigures', true, ...
    'saveFigures', true, ...
    'force', true);
```

The manufacturing utility reuses the capMaker scalp mesh cache reported by the
layout, places all selected tES and EEG holders, builds edge rails, subtracts
tetrahedral gel/electrode keepouts from the holder centers, creates PLA
underfill, and writes TPE/PLA STL files under the ignored capMaker output
folder. The recommended retention workflow uses `strapMode='none'` with
`velcroAnchorMode='file'` so the cap includes reinforced loops for external
hook-and-loop straps. `acsPlanVelcroAnchors` opens with six automatic anchors:
caudolateral, preauricular, and rostrolateral on both sides. Shift-click a
visible scalp vertex to move the active loop; the saved plan carries both the
anchor coordinates and loop geometry used by the STL build. A saved plan is
reused only when the same output file is requested, the source mesh fingerprint
still matches, and `force=false`. Use `editMode='always'` to refine previously
saved positions without changing the output file.

The final voxel stage automatically carves each loop's open ellipse through
overlapping rails. Use `velcroSlotClearanceMm` to adjust passage clearance, or
set `velcroSlotCarve=false` only for legacy/debug output.
Loop and attachment-pad occupancy lying inside the scalp is also removed before
fusion, so the rigid pad is flush on the cap interior. This uses localized
point-in-polyhedron tests rather than voxelizing the complete scalp. Set
`velcroScalpUndersideCarve=false` only for legacy/debug output.

`holderSupportMode='nearestRail'` adds short support struts from each electrode
holder to nearby cap rails so the manufacturing mesh does not depend on the
decimated scalp mesh preserving a convenient edge under every holder. The
supports are selected to spread around each holder by at least
`holderSupportMinAngleDeg` when possible; `holderBridgeMode='auto'` adds
holder-to-holder stabilizer struts for holders whose rail-only supports still
approach from a narrow angle.

Printed chin straps remain available as a legacy option when explicitly needed.
`strapMode='earRostral'` estimates lateral strap anchors from the rostral edge
of the saved ear exclusion spheres; `strapMode='bboxLateral'` recovers the
older bounding-box heuristic. Legacy chin straps use
`strapCorrStyle='rectilinear'` by default, which voxelizes the strap as an
explicit square-wave sequence of vertical and horizontal bars. Set
`strapCorrStyle='swept'` only to recover the older swept-prism strap body.
`strapCorrFitIntegerCycles=true` adjusts each strap section to contain whole
cycles so partial corrugations are not left at the cap or ring end.
Use `acsPreviewChinStrapGeometry` for a strap-only tuning loop before running
the full manufacturing build. The interactive tuner shows both the triangulated
surface and the underlying voxel raster, and its Done button saves a MAT file
containing `manufacturingNameValuePairs` plus the explicit `strapOptions` and
`strapFrameOptions`.

```matlab
strapPreview = acsPreviewChinStrapGeometry( ...
    'outputDir', fullfile(pwd, 'outputs', 'debug', 'chinStrapPreview'), ...
    'previewTag', 'M2107_chinStrapTune', ...
    'parameterFile', fullfile(pwd, 'outputs', 'debug', ...
        'chinStrapPreview', 'M2107_chinStrapTune_params.mat'), ...
    'voxelSizeMm', 0.75, ...
    'interactive', true);
```

For reference, the final manufacturing call with a previously saved Velcro plan
has this minimal form:

```matlab
manufacturing = acsBuildCapMakerManufacturingStl(combinedLayout, ...
    'manufacturingTag', 'M2107_tes8_eeg8_cap_v01', ...
    'strapMode', 'none', ...
    'velcroAnchorMode', 'file', ...
    'velcroAnchorFile', velcroPlan.outputFile, ...
    'showFigures', true, ...
    'saveFigures', true, ...
    'force', true);
```

The full STL build uses `inpolyhedron` during voxel fusion/carving. The public
repo includes `acsUtilities/inpolyhedron.m`, and `setNHPulsePath` adds it with
the rest of the utilities. If you use a different copy, set
`inpolyhedronPath`, `ACS_INPOLYHEDRON_PATH`, or an entry in
`local.paths.json`. A typical local config entry is:

```json
"inpolyhedronPath": "/path/to/inpolyhedron.m"
```

During manufacturing, `preserveFusedTpeOccupancy=true` keeps the fused TPE
raster authoritative through electrode-hole carving. This avoids a
fuse-to-mesh-to-raster round trip that can corrupt voxel-native corrugations
such as chin straps. `carveCloseVox=0` is recommended for corrugated straps;
use `acsDiagnoseChinStrapManufacturing` to compare intended strap voxels
against fused, carved, cropped, and PLA raster stages.

Pass a custom TPM explicitly when needed:

```matlab
out = acsSegmentAnatomyWithTpm('M2107', ...
    'tpmFile', 'C:/path/to/customMonkeyTpm.nii');
```

For debugging genuinely incorrect headers, `planeVoxelDims` can manually set
the displayed sagittal, coronal, and axial slice dimensions:

```matlab
out = acsSegmentAnatomyWithTpm('M2107', ...
    'planeVoxelDims', [3 2 1], ...
    'showFigures', true);
```

## TPM QC

Use `acsViewTpm` to inspect the macaque TPM itself before using it for
subject segmentation. It samples slices through the TPM with SPM, so it does
not need to load a multi-gigabyte TPM fully into memory.

```matlab
out = acsViewTpm('showFigures', true, 'saveFigures', true);
```

Or pass a specific TPM:

```matlab
out = acsViewTpm('C:/path/to/defaultMonkeyTpm.nii', ...
    'showFigures', true, ...
    'saveFigures', true);
```

## SPM TPM Alignment QC

Use `acsViewSpmTpmAlignment` after a segmentation run to inspect the TPM
as SPM has aligned it into the subject T1 grid. This helps distinguish a
bad TPM from a bad subject-to-TPM transform or a later tissue-class output
problem.

```matlab
out = acsViewSpmTpmAlignment('M2107', ...
    'segmentationTag', 'affreg_mni', ...
    'planeMode', 'spm', ...
    'showFigures', true, ...
    'saveFigures', true);
```

By default it creates separate affine-only and final-warp figures in raw
SPM subject voxel dimensions. Each figure shows the T1, the aligned TPM
sampled in the same subject grid, and T1 plus TPM contours for the same
slices. After the raw SPM-space check looks sensible, use
`'planeMode','anatomical'` with `anatomicalAxes` or `planeVoxelDims` for a
presentation view with anatomical labels.

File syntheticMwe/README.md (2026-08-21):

# Synthetic MWE Data Tools

This folder holds developer utilities for creating small synthetic inputs for
NHPulse minimal working examples. These are intentionally separate from the
main project functions so the public tutorial fixtures can be refined without
muddying the scientific pipeline.

## Current Entry Point

For a quick end-to-end format/plumbing check that stops before expensive
ROAST solves:

```matlab
setNHPulsePath;
smokeOut = nhpulseRunSyntheticSmokeTest( ...
    'force', true, ...
    'showFigures', true);
```

To create only the synthetic input files:

```matlab
setNHPulsePath;
syntheticOut = nhpulseCreateSyntheticRoastReadyData( ...
    fullfile(pwd, 'outputs', 'syntheticMwe', 'nhpulseSynthetic01'), ...
    'force', true, ...
    'showFigure', true);
```

The generator writes a small cartoon macaque-head dataset:

- `*_T1.nii`: T1-like image volume.
- `*_T1_T1orT2_SPM_masks.nii`: ROAST-compatible hard-label mask.
- `*_syntheticReport.mat/json`: a report with a `roastReady` struct.
- optional paired synthetic model/phone-scan fiducial files.
- optional synthetic phone-scan-like PLY/MAT surface.

The walkthrough also uses `nhpulseCreateSyntheticHeadpostTrace` to make a toy
implant trace in capMaker print millimeters. That trace is a stand-in for
Polhemus, phone-scan, or other subject-specific implant-localization data.

The ROAST label convention is:

1. white
2. gray
3. CSF
4. bone
5. skin
6. air

## Intended MWE Boundary

The public walkthrough starts from `syntheticOut.roastReady` rather than from
DICOM import or SPM segmentation. By default it uses dummy lead fields to stay
small and deterministic while still exercising the NHPulse/capMaker
layout-growth and manufacturing paths. Use `nhpulseExampleConfig` to switch
between reviewer presets:

```matlab
cfg = nhpulseExampleConfig('syntheticReviewer'); % interactive, dummy fields
cfg = nhpulseExampleConfig('syntheticFast');     % noninteractive, dummy fields
cfg = nhpulseExampleConfig('syntheticRoast');    % noninteractive, real ROAST/GetDP
```

After running `exampleWalkthrough.m`, verify the expected product files with:

```matlab
verification = nhpulseVerifySyntheticWalkthrough();
```

These data are for software checks only. They are not anatomically realistic
and should never be used for scientific simulation claims.

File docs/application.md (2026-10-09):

# NHPulse Application Shell

`nhpulseApp` is a thin, manifest-backed front end for reopening an NHPulse
project. It does not reimplement the scientific or manufacturing tools. It
selects explicit artifacts from one run and launches the existing specialized
GUIs through the stable service layer.

Start it after configuring the MATLAB path:

```matlab
setNHPulsePath;
P = acsPaths();
app = nhpulseApp(P.outputRoot);
```

With no argument, `nhpulseApp` uses the configured `P.outputRoot` when it is
available. Ordinary app refreshes validate manifest structure, file existence,
and dependency revisions without rehashing every large artifact. Run
`nhpulseCheckManifest(manifestFile, 'verifyContent', true)` when a full content
integrity check is required, or launch the app with
`nhpulseApp('verifyContent', true)`.

The project field should point to the folder that contains the `manifests/`
directory and the artifacts referenced by those manifests. Use **Browse** or
type another root and select **Open**.

## Interface

- **Subject** filters runs using `manifest.metadata.subjectId`.
- **Run** selects the exact manifest used by every launch action.
- **Stage** shows the workflow in dependency order and reports whether each
  stage is current, partial, stale, missing, or not started.
- **Artifacts** lists registered products for the selected run. Green rows are
  current; amber or red rows require attention.
- **Unregistered outputs** appears as a temporary run when recognizable files
  predate the manifest system. Select one inferred subject and choose
  **Import existing outputs** to create an inventory manifest. Importing does
  not move files or guess unknown parent relationships.
- **Inspect selected** opens an existing specialized inspector when one is
  registered for that artifact type.
- **Open file folder** reveals the selected artifact without changing it.

Interactive launch buttons currently cover printer-bed cropping, anatomical
exclusions, model fiducials, target selection, headpost placement, Velcro
anchor planning, and manufacturing inspection. Accepted outputs are recorded
immediately. If an upstream decision changes, manifest checks mark dependent
products stale rather than silently treating them as compatible.

The shell intentionally leaves long or highly configurable operations, such as
lead-field generation and montage optimization, in the documented service and
walkthrough APIs for now. Those stages still appear in workflow navigation and
artifact status reporting.

Current smoke tests and walkthroughs write manifests automatically. The import
path is primarily for products created by older NHPulse versions. The default
`discoverLegacy='auto'` scans for these files only when the selected project has
no manifests. To inspect a mixed project containing both registered and older
outputs, launch `nhpulseApp(P.outputRoot, 'discoverLegacy', 'always')`.

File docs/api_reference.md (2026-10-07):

# API Reference

This is a high-level map of the public-facing functions most useful to new
users. MATLAB help text in each function remains the authoritative interface
description.

## Setup And Configuration

- `setNHPulsePath`: add repository folders and known local dependency folders.
- `nhpulseConfigureLocalPaths`: create or update `local.paths.json`.
- `nhpulseCheckDependencies`: print dependency availability and install links.
- `nhpulseClearMacQuarantine`: clear macOS quarantine attributes on configured
  dependencies.
- `nhpulseExampleConfig`: return named synthetic walkthrough presets.

## Synthetic MWE

- `nhpulseCreateSyntheticRoastReadyData`: generate synthetic T1, hard-label
  mask, fiducials, and scan-like geometry.
- `nhpulseCreateSyntheticHeadpostTrace`: create a toy headpost trace.
- `nhpulseRunSyntheticSmokeTest`: quick synthetic installation smoke test.
- `nhpulseVerifySyntheticWalkthrough`: verify products from the full synthetic
  walkthrough.

## Projects And Provenance

- `nhpulseApp`: select projects, subjects, and runs; navigate workflow stages;
  inspect artifact status; and launch specialized GUIs.
- `nhpulseArtifactTypes`: inspect or extend the artifact hierarchy.
- `nhpulseOpenProject`: load all run manifests and inventory recognizable
  unregistered outputs without modifying them.
- `nhpulseProjectStatus`: report current, stale, missing, incompatible, and
  unregistered artifacts in one table.
- `nhpulseDiscoverLegacyArtifacts`: perform the read-only legacy output scan.
- `nhpulseImportLegacyArtifacts`: preview or explicitly register selected
  legacy files in place; dry-run mode is the default.
- `nhpulseCreateManifest`, `nhpulseRegisterArtifact`, and
  `nhpulseSaveManifest`: record a new run and its dependency edges.
- `nhpulseCheckManifest`: validate files, fingerprints, dependency freshness,
  cycles, and known artifact-type relationships.

## Stable Pipeline Services

- `nhpulseCreateProjectContext`: identify one project root and run manifest.
- `nhpulseResolveArtifact`: resolve and validate an artifact key or handle.
- `nhpulseServiceBuildScalp`, `nhpulseServiceCropScalp`, and
  `nhpulseServiceDefineExclusions`: prepare printable subject geometry.
- `nhpulseServicePlaceHeadpost`: place/register a headpost and its keepout.
- `nhpulseServiceBuildFitCheck`: export/register a sparse PLA fit-check cap.
- `nhpulseServiceDefineFiducials` and `nhpulseServiceSelectTarget`: register
  spatial landmarks and the brain target consumed by later stages.
- `nhpulseServiceBuildCandidateLayout`, `nhpulseServiceGenerateLeadField`, and
  `nhpulseServiceOptimizeMontage`: perform registered targeting stages.
- `nhpulseServiceGrowCandidateLayout`: propose/register an expanded candidate
  layout from the current sparse solution.
- `nhpulseServiceBuildCombinedLayout`, `nhpulseServicePlanRetention`, and
  `nhpulseServiceBuildManufacturing`: produce the final layout and STLs.

See [Stable Pipeline Services](services.md) for the service contract and call
sequence.

## Scalp And Registration

- `acsBuildRoastScalpSkinCache`: build a capMaker-compatible scalp cache from
  ROAST labels.
- `acsCropWarpedSkinCacheToPrinterBed`: crop a full-head scalp into printer-bed
  coordinates.
- `acsRegisterPhoneScanToCapMakerFrame`: register phone/PLY scans to the MRI
  or capMaker frame.
- `acsWarpScalpSurfaceToPhoneScan`: warp a scalp surface to phone-scan data.
- `acsSelectModelFiducials`, `acsSelectPhoneScanFiducials`: fiducial pickers.

## Exclusions And Implants

- `acsSelectEarExclusionSpheres`: define ears and painted vertex exclusions.
- `acsPlanHeadpostPlacement`: place and refine a simplified headpost mesh.
- `acsMakeHeadpostExclusionFromPlacement`: derive a tight cap keepout from a
  placed headpost.
- `acsPlanChamberPlacement`: plan cylindrical recording chamber placement.

## Layout And Modeling

- `acsMakeRoastCapMakerLayout`: place initial capMaker/ROAST custom locations.
- `acsGenerateRoastLeadField`: run ROAST lead-field generation for a layout.
- `acsGenerateDummyRoastLeadField`: create development-only dummy lead fields.
- `acsOptimizeSparseRoastLeadField`: select a sparse active tES montage.
- `acsProposeRoastCandidateGrowth`: propose new candidate sites with surrogate
  prediction and UCB-style acquisition.
- `acsAssembleTesEegCapMakerLayout`: interleave EEG electrodes around selected
  tES sites.
- `acsBuildTesToEegTransferMatrix`: perform and cache the independent direct
  solves that map fixed-layout tES currents to referenced EEG voltages.
- `acsOptimizeOrthogonalTesEegTopography`: find a current-balanced active
  control whose predicted EEG artifact is orthogonal to the target-optimized
  stimulus under matched current limits.
- `acsPrepareTesEegContrastProtocol`: resolve a finalized cap by tag from a
  clean workspace and export target-optimized and EEG-orthogonal signed
  current vectors in a stable MAT/CSV protocol.
- `acsShowTesStimulationParameters`: reload a saved sparse/layout/manufacturing
  product and display the final tES current recipe, with optional replay of
  saved electric-field and EEG topography figures.

## Manufacturing And QC

- `acsBuildCapMakerFitCheckStl`: create a sparse PLA fit-check scaffold.
- `acsPlanVelcroAnchors`: propose and refine six Velcro-loop attachment
  anchors around the cap edge.
- `acsBuildCapMakerManufacturingStl`: export dual-material cap STL products.
- `acsInspectCapMakerManufacturingGeometry`: inspect scalp/cap/electrode
  geometry and orientation diagnostics.
- `acsPreviewChinStrapGeometry`: interactively preview chin strap parameters.

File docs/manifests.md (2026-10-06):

# Run Manifests And Artifact Provenance

NHPulse run manifests inventory products that belong together without moving,
renaming, or changing the cache behavior of existing pipeline files. The first
manifest schema is deliberately generic so new artifact types can be recorded
before a type-specific validator is added.

## Minimal Example

```matlab
manifest = nhpulseCreateManifest(outputDir, 'Subject M2107 cap build', ...
    'metadata', struct('subjectId', 'M2107'));

[manifest, anatomy] = nhpulseRegisterArtifact(manifest, ...
    'nhpulse.anatomy', t1File, 'label', 'T1 anatomy');

[manifest, segmentation] = nhpulseRegisterArtifact(manifest, ...
    'nhpulse.segmentation', segmentationFile, ...
    'parents', nhpulseArtifactRef(anatomy, 'sourceAnatomy'));

manifestFiles = nhpulseSaveManifest(manifest);
report = nhpulseCheckManifest(manifestFiles.mat);
```

`nhpulseSaveManifest` writes both a MATLAB MAT file and readable JSON. By
default they are stored under:

```text
<projectRoot>/manifests/<runId>/nhpulse-manifest.mat
<projectRoot>/manifests/<runId>/nhpulse-manifest.json
```

Files within `projectRoot` are recorded with relative paths. Their content
fingerprints therefore remain meaningful if the entire output tree is moved to
another machine. When the old root is unavailable, `nhpulseLoadManifest`
searches upward from the manifest file for the relocated artifact tree. The
default `fingerprintMode='auto'` uses SHA-256 for files through 256 MB and a
fast, clearly labeled size-and-modification-time fingerprint for larger files.
Users can explicitly request either mode when registering an artifact.

## Artifact Hierarchy

`nhpulseArtifactTypes` defines the built-in dependency vocabulary. Its stages
follow the stable-to-changeable structure of an NHPulse project:

1. anatomy and segmentation;
2. registration, scalp models, crop planes, implants, and exclusions;
3. targets, candidate layouts, lead fields, and optimized montages;
4. combined tES/EEG layouts and predictions;
5. manufacturing geometry, printable STLs, and experimental protocols.

Each definition records a stage, display order, parent policy, accepted parent
types, normal file extensions, and conservative filename patterns for legacy
discovery. The registry is extensible:

```matlab
custom = struct( ...
    'type', 'myLab.behavioralProtocol', ...
    'label', 'Behavioral protocol', ...
    'stage', 'experiment', ...
    'stageOrder', 96, ...
    'parentPolicy', 'listed', ...
    'allowedParentTypes', {{'nhpulse.stimulationProtocol'}});

registry = nhpulseArtifactTypes('additionalTypes', custom);
report = nhpulseCheckManifest(manifest, 'artifactTypes', custom);
```

Omitted definition fields receive permissive defaults. Unknown artifact types
continue to receive generic checks, so adding a new product never requires a
schema migration before it can be recorded.

## Project Inspection

Open an existing output tree and summarize all known runs with:

```matlab
project = nhpulseOpenProject(outputRoot);
status = nhpulseProjectStatus(project);
```

`nhpulseOpenProject` loads each `nhpulse-manifest.mat`, checks its dependency
graph and fingerprints, and read-only scans the `outputs/` subtree for
recognizable files not represented by a manifest. `nhpulseProjectStatus`
reports five states:

- `current`: the file, fingerprint, parents, and known type relationships agree;
- `stale`: the file or an upstream parent has changed;
- `missing`: the recorded file cannot be found;
- `incompatible`: a known type has an invalid extension or parent type;
- `unregistered`: a legacy file was recognized but has no manifest record.

Legacy discovery deliberately does not infer dependency edges. Review a
dry-run import before creating an inventory manifest:

```matlab
preview = nhpulseImportLegacyArtifacts(project);  % dry run by default
imported = nhpulseImportLegacyArtifacts(project, ...
    'selection', {'nhpulse.manufacturingStl'}, 'dryRun', false);
```

Importing fingerprints and registers the selected files in place. It does not
move or rename outputs, and it labels the resulting manifest as a legacy
inventory whose parent relationships remain unspecified.

## Generic Checks

`nhpulseCheckManifest` currently checks:

- artifact files exist,
- current fingerprints match recorded fingerprints,
- artifact IDs are unique,
- parent IDs resolve,
- recorded parent revisions still match,
- the dependency graph contains no cycles, and
- stale or missing state propagates to downstream artifacts.

Artifact types are namespaced strings such as `nhpulse.scalpModel` or
`nhpulse.optimizedMontage`. Known types additionally receive extension and
parent-policy checks. Unknown types receive the generic checks and remain
valid.

## Current Scope

This recorder is additive. Existing output discovery, filenames, and cache
checks remain authoritative for the current pipeline. The synthetic walkthrough
creates a manifest after its normal verification step so the dependency model
can be exercised before it is used to reorganize real subject outputs.

Run `nhpulseTestManifestRecorder` and `nhpulseTestProjectInspection` for fast
self-tests that use only temporary files. Together they verify MAT/JSON round
trips, changed-parent detection, stale-child propagation, extensible artifact
types, project opening, legacy discovery, dry-run import, and incompatible
parent detection.

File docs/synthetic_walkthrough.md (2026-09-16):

# Synthetic Walkthrough

The public walkthrough is [../exampleWalkthrough.m](../exampleWalkthrough.m).
It starts from generated synthetic anatomy so reviewers do not need private MRI,
phone scan, or lead-field data.

## Before Running

From the repository root:

```matlab
setNHPulsePath;
P = nhpulseConfigureLocalPaths('profile', 'syntheticMwe');
report = nhpulseCheckDependencies();
```

Then open `exampleWalkthrough.m` and run cells in order.

## Presets

The walkthrough uses `nhpulseExampleConfig` so reviewers do not have to type a
long list of option names.

```matlab
cfg = nhpulseExampleConfig('syntheticReviewer');
```

Supported presets:

- `syntheticReviewer`: default public path; opens GUI steps and uses dummy lead
  fields.
- `syntheticFast`: noninteractive dummy-leadfield run for repeat testing.
- `syntheticRoast`: noninteractive run that uses real ROAST/GetDP lead-field
  solves on the toy head.

Any preset field can be overridden:

```matlab
cfg = nhpulseExampleConfig('syntheticFast', ...
    'showFigures', false, ...
    'nGrowthSteps', 1);
```

## Walkthrough Stages

1. Create synthetic ROAST-ready T1 and hard-label mask files.
2. Build a ROAST-derived scalp surface cache.
3. Crop the scalp into the capMaker printer-bed frame.
4. Define ear and painted manufacturing exclusions.
5. Place a toy headpost and derive a cap keepout.
6. Export a sparse PLA fit-check STL.
7. Mark or reuse model fiducials.
8. Select a target voxel.
9. Build the initial tES candidate layout.
10. Grow tES candidates with dummy or ROAST lead fields.
11. Interleave EEG electrodes around the optimized tES montage.
12. Export final dual-material PLA/TPE cap STLs with Velcro attachment loops.
13. Verify generated outputs with `nhpulseVerifySyntheticWalkthrough`.

## What Each Step Is Trying To Accomplish

The walkthrough is not just a file-conversion demo. It is meant to show how a
researcher goes from a head model to a manufacturable cap while preserving the
geometry needed for electrical modeling.

### 01 - Synthetic Anatomy

Goal: create a tiny, non-sensitive stand-in for a macaque MRI and tissue-label
volume. The synthetic head lets reviewers exercise the software without real
animal MRI, phone-scan, or lead-field data.

Check: the QC figure should show a simple head-like object with nested tissue
labels. It is intentionally cartoon-like and should not be interpreted as a
scientific model.

### 02 - ROAST-Derived Scalp Surface

Goal: establish the scalp surface that will be used by the capMaker side of
the workflow. In real projects this surface is the common reference for cap
manufacturing, electrode placement, and alignment to additional measurements.

Check: the extracted surface should be a continuous outer head/scalp shell
rather than disconnected fragments.

### 03 - Crop To Printer-Bed Coordinates

Goal: define what part of the head should receive a cap. The crop plane becomes
the 3D-printer bed (`Z=0`) in capMaker coordinates. Rubber/TPE cap geometry is
built only over scalp points above this plane, and later steps keep cap rails
and holders away from the cropped edge by user-configurable margins.

What the user is deciding: where the cap should end. For an EEG/tES cap, the
crop should include the top-level scalp that the cap should cover, while
excluding ventral face/neck regions that are not intended to be part of the
cap.

Check: the cropped mesh should look like the intended cap footprint. It is fine
to be conservative; ears, face regions, implants, and other local keepouts are
handled in later steps.

### 04 - Ear And Painted Exclusions

Goal: mark areas where the cap should not be built even though they survived
the crop. Ears and facial regions can be sensitive, highly curved, or physically
incompatible with electrodes and rails.

What the user is deciding: place spherical exclusions around ears, and paint
specific mesh vertices on the face or other local regions that should not be
used as electrode sites or rail endpoints.

Check: valid scalp vertices should remain over the intended dorsal cap region,
and excluded vertices should cover ears/face without swallowing the whole cap.

### 05 - Headpost Placement And Keepout

Goal: represent cranial implants that affect cap manufacturing and, optionally,
electrical modeling. Neurophysiology animals often have titanium headposts or
other implants. The cap should not be built over the exposed post, and the
implant geometry may be relevant to current-flow models.

What the user is deciding: confirm or refine a simplified headpost placement.
The synthetic demo creates a toy circular implant trace; real projects may use
Polhemus traces, phone scans, CAD/STL models, or other measurements.

Check: the keepout should surround the exposed cylindrical/post portion. For
manufacturing, the keepout is deliberately tighter than the entire buried base
because scalp can often cover implant straps or bases.

### 06 - PLA Fit-Check STL

Goal: make a quick physical scaffold before committing to a long dual-material
print. The fit-check cap tests gross shape and exclusion geometry with a sparse
PLA rail network.

Check: the scaffold should cover the intended cap area, respect ear/implant
keepouts, and include small markers where electrodes would be placed when
requested.

### 07 - Fiducials

Goal: define anatomical landmarks that let measurements from different devices
share a reference frame. Fiducials are especially useful when registering MRI,
digitizer traces, phone scans, or physical measurements.

Check: selected points should correspond to the intended anatomical labels.
Exact labels can be project-specific, but repeated use should be consistent.

### 08 - Brain Target

Goal: choose the brain location the tES montage should try to stimulate. In a
real experiment this might come from an atlas, MRI anatomy, functional data, or
planned recording chamber trajectory.

Check: the target should lie in the modeled brain compartment, and the desired
field orientation should make sense for the scientific question.

### 09-10 - tES Candidate Layout And Growth

Goal: start with a small set of legal candidate electrodes, model or approximate
their lead fields, solve a sparse targeting problem, and then propose additional
candidate sites that may improve targeting.

What the algorithm is doing: the growth step balances predicted stimulation
quality with exploration of under-sampled scalp regions. The default synthetic
run uses dummy lead fields for speed; `syntheticRoast` exercises real ROAST/GetDP
solves.

Check: proposed candidates should stay on legal scalp and outside keepouts.
Sparse optimization should select a small active montage from the candidates.

### 11 - EEG Interleaving

Goal: add EEG electrodes to the remaining cap area without colliding with tES
contacts, ears, implants, or other exclusions. These EEG sites are chosen for
approximately even scalp coverage rather than stimulation targeting.

Check: EEG sites should be distributed over the remaining legal scalp, with no
obvious collisions or placements on excluded regions.

### 11.5 - tES Stimulation Parameters

Goal: display the final tES current recipe in a table that can be reviewed
later from a clean workspace. The same utility can be called with no arguments
for a file picker, or with a saved layout/manufacturing MAT file or tag.

Check: selected tES channels should have balanced anodal and cathodal current,
and the source electrode names should match the sparse optimization result.

### 12 - Dual-Material Manufacturing STL

Goal: convert the layout into printable geometry: TPE/rubber rails, electrode
holders, and Velcro-loop strap anchors, plus PLA support/underfill for
printing. This is the stage where a cap becomes a slicer-ready object.

Check: electrode holders should be clear through to the scalp, rails should be
connected, keepouts should be respected, no holders should be clipped by the
printer bed or placed on the underside of the cap, and Velcro-loop slots should
remain open. The recommended workflow runs `acsPlanVelcroAnchors` before this
step and exports the final cap with `strapMode='none'` plus
`velcroAnchorMode='file'`. Printed chin straps are retained as a legacy option
for workflows that explicitly need them.

### 13 - Verification

Goal: give reviewers a lightweight file-level check that the walkthrough
produced the expected classes of outputs.

Check: all required products should pass. Missing optional real lead-field
results are expected if the walkthrough was run in dummy mode.

## Outputs

By default, products are written under:

```text
outputs/syntheticMwe/nhpulseSyntheticDemo
```

The important reviewer outputs are synthetic anatomy, scalp caches, exclusions,
headpost placement/keepout files, a target voxel selection, a fit-check STL,
tES/EEG layout reports, final PLA/TPE STL files, and QC figures.

## Verifying A Completed Run

```matlab
verification = nhpulseVerifySyntheticWalkthrough();
```

If you ran a custom output directory:

```matlab
verification = nhpulseVerifySyntheticWalkthrough(cfg.outputDir, ...
    'subjectId', cfg.subjectId);
```

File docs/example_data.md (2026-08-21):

# Example Data

The public repository uses generated synthetic data instead of committing real
MRI, phone/LiDAR scan, lead-field, or manufacturing products.

## Why Synthetic Data

Real subject MRI and lead-field outputs are large. Phone/LiDAR scans and
photographs can also contain sensitive animal imagery. Generated synthetic data
let reviewers exercise the software path without downloading private data or
large binary products.

## Current Public Fixture

The synthetic generator writes a cartoon NHP-like head:

- `*_T1.nii`: T1-like image volume.
- `*_T1_T1orT2_SPM_masks.nii`: ROAST-compatible hard-label mask.
- model and phone fiducials.
- phone-scan-like mesh/point products.
- optional toy headpost traces.

Create the inputs through the smoke test or walkthrough:

```matlab
smokeOut = nhpulseRunSyntheticSmokeTest('force', true);
```

or:

```matlab
syntheticOut = nhpulseCreateSyntheticRoastReadyData( ...
    fullfile(pwd, 'outputs', 'syntheticMwe', 'nhpulseSyntheticDemo'), ...
    'subjectId', 'nhpulseSyntheticDemo', ...
    'force', true);
```

## Real Data Guidance

Keep real subject inputs outside git. Configure private roots with
`nhpulseConfigureLocalPaths`, and add subject-specific path entries to
`local.paths.json` only on the machine where those data live.

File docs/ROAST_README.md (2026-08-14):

# ROAST: Realistic vOlumetric-Approach-based Simulator for Transcranial electric stimulation

1. [Getting started](#1-getting-started)
2. [How to use `roast`](#2-how-to-use-roast)
   - [2.1 Synopsis of `roast`](#21-synopsis-of-roast)
   - [2.2 Examples on `roast`](#22-examples-on-roast)
3. [How to use `roast_target`](#3-how-to-use-roast_target)
   - [3.1 Synopsis of `roast_target`](#31-synopsis-of-roast_target)
   - [3.2 Examples on `roast_target`](#32-examples-on-roast_target)
4. [More notes on the `capLayout.pdf` file](#4-more-notes-on-the-capLayoutpdf-file)
5. [Outputs of ROAST software](#5-outputs-of-roast-software)
   - [5.1 Outputs of `roast`](#51-outputs-of-roast)
   - [5.2 Outputs of `roast_target`](#52-outputs-of-roast_target)
6. [Review of simulation data](#6-review-of-simulation-data)
   - [6.1 Review of data from `roast`](#61-review-of-data-from-roast)
   - [6.2 Review of data from `roast_target`](#62-review-of-data-from-roast_target)
7. [How to ask questions](#7-how-to-ask-questions)
8. [Acknowledgements](#8-acknowledgements)
9. [Notes](#9-notes)
10. [License](#10-license)

## 1. Getting started

After you download the zip file, unzip it, launch your Matlab, make sure you are under the root directory of ROAST (i.e., you can see `example/`, `lib/`, and all other files), and then enter:

`roast`

This will demo a modeling process on the MNI152 head. Specifically, it will use the T1 image of the [6th gen MNI-152 head](http://nist.mni.mcgill.ca/?p=858) to build a TES model with anode on Fp1 (1 mA) and cathode on P4 (-1 mA).

There are 3 main functions that you can call: `roast()`, `roast_target()` and `reviewRes()`, which will be covered in [Section 2](#2-how-to-use-roast), [Section 3](#3-how-to-use-roast_target), and [Section 6](#6-review-of-simulation-data), respectively.

## 2. How to use `roast`

### 2.1 Synopsis of `roast`

`roast(subj,recipe,varargin)`

`subj`: file name (can be either relative or absolute path) of the MRI of
the subject that you want to run simulation on. The MRI can be either T1
or T2. If you have both T1 and T2, then put T2 file in the option `'T2'`
(see below options for details). If you do not have any MRI but just want
to run ROAST for a general result, you can use the default subject the
[MNI152 averaged head](http://nist.mni.mcgill.ca/?p=858) (see [Example 1](#example-1)) or the [New York head](https://www.parralab.org/nyhead/) (see [Example 2](#example-2)).

`recipe`: how you want to ROAST the subject you specified above. Default
recipe is anode on Fp1 (1 mA) and cathode on P4 (-1 mA). You can specify
any recipe you want in the format of `electrodeName-injectedCurrent` pair
(see [Example 3](#example-3)). You can pick any electrode from the 10/20, 10/10, 10/05, BioSemi-256, or EGI HCGSN-256 EEG system (see the file [`capLayout.pdf`](./capLayout.pdf) under the root directory of ROAST). The unit of the injected current is in milliampere (mA). Make sure
they sum up to 0. You can also place electrodes at customized locations
on the scalp. See [Example 5](#example-5) for details. You can also use a special recipe called "leadField", so that ROAST will automatically generate all the data that will allow you to call `roast_target()` later to perform targeted TES. See [Example 26](#example-26) and [How to use `roast_target`](#3-how-to-use-roast_target).

`varargin`: Options for ROAST can be entered as `Name-Value` pairs in the 3rd argument 
(available from ROAST v2.0). The syntax follows the Matlab convention (see [`plot()`](https://www.mathworks.com/help/matlab/ref/plot.html#namevaluepairarguments) for example).

*If you do not want to read the detailed info on the options below, you can go to [Example 25](#example-25) for quick reference.*

`'capType'` -- the EEG system that you want to pick any electrode from.  
`'1020' | '1010' (default) | '1005' | 'BioSemi' | 'EGI'`  
You can also use customized electrode locations you defined. Just provide
the text file that contains the electrode coordinates. See below [Example 5](#example-5) for details.

`'elecType'` -- the shape of electrode.  
`'disc' (default) | 'pad' | 'ring'`  
Note you can specify different shapes to different electrodes, i.e., you
can place different types of electrodes at the same time. See below
[Example 6](#example-6) for details.

`'elecSize'` -- the size of electrode.  
All sizes are in the unit of millimeter (mm). For disc electrodes, sizes
follow the format of `[radius height]`, and default size is `[6mm 2mm]`; 
for pad electrodes, sizes follow the format of `[length width height]`, and
 default size is `[50mm 30mm 3mm]`; for ring electrodes, sizes follow the 
format of `[innerRadius outterRadius height]`, and default size is `[4mm 6mm 2mm]`.

If you're placing only one type of electrode (e.g., either disc, or pad,
or ring), you can use a *one-row* vector to customize the size, see [Example
7](#example-7); if you want to control the size for each electrode separately
(provided you're placing only one type of electrode), you need to specify
the size for each electrode correspondingly in a *N-row* matrix, where *N* is
the number of electrodes to be placed, see [Example 8](#example-8); if you're placing
more than one type of electrodes and also want to customize the sizes,
you need to put the size of each electrode in a *1-by-N* cell (put `[]` for
any electrode that you want to use the default size), where *N* is the number
of electrodes to be placed, see [Example 9](#example-9).

`'elecOri'` -- the orientation of pad electrode (ONLY applies to pad electrodes).  
`'lr' (default) | 'ap' | 'si' | direction vector of the long axis`  
For pad electrodes, you can define their orientation by giving the
direction of the long axis. You can simply use the three pre-defined keywords:  
- `'lr'`--long axis going left (l) and right (r);
- `'ap'`--long axis pointing front (anterior) and back (posterior);
- `'si'`--long axis going up (superior) and down (inferior).  
For other orientations you can also specify the direction precisely by giving the direction vector of the long axis.

If you're placing pad electrodes only, use the pre-defined keywords
([Example 10](#example-10)) or the direction vector of the long axis ([Example 11](#example-11)) to
customize the orientations; if you want to control the
orientation for each pad electrode separately, you need to specify
the orientation for each pad correspondingly using the pre-defined
keywords in a *1-by-N* cell ([Example 12](#example-12)) or the direction vectors of the
long axis in a *N-by-3* matrix ([Example 13](#example-13)), where *N* is the number of pad 
electrodes to be placed; if you're placing more than one type of electrodes
and also want to customize the pad orientations, you need to put the
orientations into a *N-by-3* matrix ([Example 14](#example-14); or just a *1-by-3* vector or a
single pre-defined keyword if same orientation for all the pads) where *N*
is the number of pad electrodes, or into a *1-by-N* cell ([Example 15](#example-15)), where *N*
is the number of all electrodes to be placed (put `[]` for non-pad electrodes).

`'T2'` -- use a T2-weighted MRI to help segmentation.  
`[] (default) | file path to the T2 MRI`  
If you have a T2 MRI aside of T1, you can put the T2 file in this option,
see [Example 16](#example-16), note you should put the T1 and T2 files in the same
directory.
If you ONLY have a T2 MRI, put the T2 file in the first argument `'subj'`
when you call roast, just like what you would do when you only have a T1.

`'multiaxial'` -- use Multiaxial (deep convolutional neural networks) for segmentation.  
`'on' | 'off' (default)`  
For heads with abnormal anatomies such as a lesion, SPM usually cannot output a correct segmentation 
that captures the lesions, and fails to align the head to the MNI space. In this case, you can use 
pre-trained deep convolutional neural networks known as the Multiaxial for modeling these abnormal anatomies. 
To use Multiaxial instead of SPM for segmentation, simply turn on this option. See [Example 17](#example-17). 
If you turn on `'multiaxial'`, please do not provide any T2 image (just providing T1 is enough), as Multiaxial 
only works with T1 images. Also if you turn on `'multiaxial'`, SPM will be disabled, and another open-source 
toolbox [NiftyReg](https://github.com/KCL-BMEIS/niftyreg) will be called to register the head MRI into the MNI space. 
Note if `'multiaxial'` is turned on, and the head MRI does not cover the lower head, we do not recommend you to 
place any electrodes on the lower head or on the neck. But if you have to do this with this MRI, please turn off 
`'multiaxial'` and do some zeropadding (see below) so that SPM will be called to extend the MRI to the lower head.

`'manualGui'` -- 3D GUI that allows users to manually check and select anatomical landmarks.  
`'on' | 'off' (default)`  
For heads with abnormal anatomies such as a lesion, you may want to manually check if the automated registration from 
either SPM or NiftyReg worked well. To do this, you can open [an interactive 3D graphical user interface (GUI)](./manualGui.png) that allows you to 
visually check if the landmarks look good on the individual head ([Example 18](#example-18)). If not, it means the registration 
did not work well, and you can adjust it by clicking the "Modify" button in the GUI to manually click the anatomical landmarks 
(Nasion, Inion, Right Ear, Left Ear, just follow the program step by step). Note if you manually select the landmarks, ROAST will 
re-align the head MRI to the MNI space based on the landmarks you select, overwrite any registration computed by SPM or NiftyReg, 
and reset the headers in the [`"_MNI.nii"` images](#51-outputs-of-roast).

`'meshOptions'` -- advanced options of ROAST, for controlling mesh parameters
(see [Example 19](#example-19)).  
5 sub-options are available:
- `meshOpt.radbound`: maximal surface element size, default 5;
- `meshOpt.angbound`: mimimal angle of a surface triangle, default 30;
- `meshOpt.distbound`: maximal distance between the center of the surface bounding circle
and center of the element bounding sphere, default 0.3;
- `meshOpt.reratio`: maximal radius-edge ratio, default 3;
- `meshOpt.maxvol`: target maximal tetrahedral element volume, default 10.  
See [iso2mesh documentation](http://iso2mesh.sourceforge.net/cgi-bin/index.cgi?Doc) for more details on these options.

`'simulationTag'` -- a unique tag that identifies each simulation.  
`dateTime string (default) | user-provided string`  
This tag is used by ROAST for managing simulation data. ROAST can
identify if a certain simulation has been already run. If yes, it will
just load the results to save time. You can leave this option empty so 
that ROAST will just use the date and time as the unique tag for the
simulation. Or you can provide your preferred tag for a specific
simulation ([Example 20](#example-20)), then you can find it more easily later. Also all the
simulation history with options info for each simulation are saved in the
log file (named as `"subjName_roastLog"`), parsed by the simulation tags.

`'resampling'` -- re-sample the input MRI to 1mm isotropic resolution.  
`'on' | 'off' (default)`  
Sometimes the input MRI has a resolution other than 1 mm, e.g., 0.6 mm.
While higher resolution can give more accurate models, the computation
will be more expensive and thus slower. If you want a faster simulation,
you can ask ROAST to resample the MRI into 1 mm isotropic resolution by
turning on this option ([Example 21](#example-21)). Also it is recommended to turn on
this option if your input MRI has anisotropic resolution (e.g., 1 mm by
1.2 mm by 1.2 mm), as the electrode size will not be exact if the model
is built from an MRI with anisotropic resolution. From ROAST v3.0, the data generated by ROAST can be loaded into the [Soterix software HD-Explore and HD-Targets](https://soterixmedical.com/research/software), if the input MRI has 1 mm resolution. Users can turn on `'resampling'` option for non-1 mm resolution MRI if they want to load the results (only the lead field) in Soterix software later for better visualization. See [Example 27](#example-27).

`'zeroPadding'` -- extend the input MRI by some amount, to avoid
complications when electrodes are placed by the image boundaries. Default
is not padding any slices to the MRI. You can ask ROAST to pad *N* empty
slices in all the six directions of the input MRI (left, right, front,
back, up and down), where *N* is a positive integer. This is very useful
when placing big electrodes on the locations close to image boundaries
([Example 22](#example-22)). This is also useful for MRIs that are cut off at the nose and thus do not cover the lower head. 
If you specify a zeropadding of, say, 60 slices, and turn off `'multiaxial'`, ROAST can automatically get the segmentation 
of the lower part of the head, see [Example 22](#example-22).

`'conductivities'` -- advanced options of ROAST, the values are stored as a 
structure, with the following field names:
- `white` (default 0.126 S/m);
- `gray` (default 0.276 S/m);
- `csf` (default 1.65 S/m);
- `bone` (default 0.01 S/m);
- `skin` (default 0.465 S/m);
- `air` (default 2.5e-14 S/m);
- `gel` (default 0.3 S/m);
- `electrode` (default 5.9e7 S/m).  
You can use this option to customize the electrical conductivity for each tissue, each electrode, as well as the
conducting medium under each electrode. You can even assign different conductivity
values to different electrodes and their conducting media (e.g., `'gel'`). See
[Example 23](#example-23) and [Example 24](#example-24) for details.

### 2.2 Examples on `roast`

#### Example 1

    roast

Default call of ROAST, will demo a modeling process on the MNI152 head.
Specifically, this will use the MRI of the MNI152 head to build a model
of transcranial electric stimulation (TES) with anode on Fp1 (1 mA) and cathode
on P4 (-1 mA). Electrodes are modeled by default as small disc electrodes.
See options below for details.

#### Example 2

    roast('nyhead')

ROAST New York head. Again this will run a simulation with anode on Fp1 (1 mA)
and cathode on P4 (-1 mA), but on the 0.5-mm resolution New York head. A decent
machine of 50GB memory and above is recommended for running New York
head. Again electrodes are modeled by default as small disc electrodes.
See options below for details.

#### Example 3

    roast('example/subject1.nii',{'F1',0.3,'P2',0.7,'C5',-0.6,'O2',-0.4})

Build the TES model on any subject with your own "recipe". You could use any 
head MRI you have in the 1st argument as `'path/to/your/subject.nii'`. Here we inject
0.3 mA at electrode F1, 0.7 mA at P2, and we ask 0.6 mA coming out of C5,
and 0.4 mA flowing out of O2. You can define any stimulation montage you want
in the 2nd argument, with `electrodeName-injectedCurrent` pair. Electrodes are
modeled by default as small disc electrodes. You can pick any electrode
from the 10/20, 10/10, 10/05, BioSemi-256, or EGI HCGSN-256 EEG system. You can find all
the electrode layouts in the file [`capLayout.pdf`](./capLayout.pdf) under the root directory of ROAST. Note the unit of
the injected current is milliampere (mA). Make sure they sum up to 0.

#### Example 4

    roast('example/subject1.nii',{'G12',1,'J7',-1},'captype','biosemi')

Run simulation on subject1 with anode on G12 (1 mA) and cathode on J7 (-1
mA) from the extended BioSemi-256 system (see [`capLayout.pdf`](./capLayout.pdf) under the root
directory of ROAST).
 
#### Example 5

    roast('example/subject1.nii',{'E12',0.25,'E7',-0.25,'Nk1',0.5,'Nk3',-0.5,'custom1',0.25,'custom3',-0.25},'captype','egi')

Run simulation on subject1 with recipe that includes: EGI electrodes
E12 and E7; neck electrodes Nk1 and Nk3 (see [`capLayout.pdf`](./capLayout.pdf)); and
user-provided electrodes custom1 and custom3. You can use a free program
called [MRIcro](https://people.cas.sc.edu/rorden/mricro/) to load
the MRI first (note do NOT use MRIcron for this as MRIcron will not give you
the true voxel coordinates) and click the locations on the scalp surface where you want
to place the electrodes, record the voxel coordinates returned by MRIcro
into a text file, and save the text file to the MRI data directory with name
`"subjName_customLocations"` (e.g., here for subject1 it's saved as
`"subject1_customLocations"`). ROAST will load the text file and place the
electrodes you specified. You need to name each customized electrode in
the text file starting with `"custom"` (e.g., for this example they're
named as `custom1`, `custom2`, etc. You can of course do
`"custom_MyPreferredElectrodeName"`). Note that you need to use the original MRI that you use to call `roast()` 
to click for the customized electrode locations (here in this example you need to load `'example/subject1.nii'`), 
even if the MRI is not in RAS orientation, or you turn on the `'resampling'` or use `'zeroPadding'` option. 
Just record whatever you get from the original MRI that you used for running ROAST, and ROAST will take care of 
all the transforms of MRI data (re-orientation into RAS, resampling or zero-padding). See [this figure](./3spaces.jpg) for details.

#### Example 6

    roast([],{'Fp1',1,'FC4',1,'POz',-2},'electype',{'disc','pad','ring'})

Run simulation on the MNI152 averaged head with the specified recipe. A disc
electrode will be placed at location Fp1, a pad electrode will be placed at FC4,
and a ring electrode will be placed at POz. The sizes and orientations will be set
as default.

#### Example 7

    roast('nyhead',[],'electype','ring','elecsize',[7 10 3])

Run simulation on the New York head with default recipe. Ring electrodes
will be placed at Fp1 and P4. The size of each ring is 7mm inner radius,
10mm outter radius and 3mm height.

#### Example 8

    roast('nyhead',{'Fp1',1,'FC4',1,'POz',-2},'electype','ring','elecsize',[7 10 3;6 8 3;4 6 2])

Run simulation on the New York head with the specified recipe. Ring electrode
placed at Fp1 will have size `[7mm 10mm 3mm]`; ring at FC4 will have size
`[6mm 8mm 3mm]`; and ring at POz will have size `[4mm 6mm 2mm]`.

#### Example 9

    roast([],{'Fp1',1,'FC4',1,'POz',-2},'electype',{'disc','pad','ring'},'elecsize',{[8 2],[45 25 4],[5 8 2]})

Run simulation on the MNI152 averaged head with the specified recipe. A disc
electrode will be placed at location Fp1 with size `[8mm 2mm]`, a pad electrode
will be placed at FC4 with size `[45mm 25mm 4mm]`, and a ring electrode will be
placed at POz with size `[5mm 8mm 2mm]`.

#### Example 10

    roast([],[],'electype','pad','elecori','ap')

Run simulation on the MNI152 averaged head with default recipe. Pad
electrodes will be placed at Fp1 and P4, with default size of `[50mm 30mm
3mm]` and the long axis will be oriented in the direction of front to back.

#### Example 11

    roast([],[],'electype','pad','elecori',[0.71 0.71 0])

Run simulation on the MNI152 averaged head with default recipe. Pad
electrodes will be placed at Fp1 and P4, with default size of `[50mm 30mm
3mm]` and the long axis will be oriented in the direction specified by the
vector `[0.71 0.71 0]`.

#### Example 12

    roast('example/subject1.nii',{'Fp1',1,'FC4',1,'POz',-2},'electype','pad','elecori',{'ap','lr','si'})

Run simulation on subject1 with specified recipe. Pad electrodes will be 
placed at Fp1, FC4 and POz, with default size of `[50mm 30mm 3mm]`. The long
axis will be oriented in the direction of front to back for the 1st pad,
left to right for the 2nd pad, and up to down for the 3rd pad.

#### Example 13

    roast('example/subject1.nii',{'Fp1',1,'FC4',1,'POz',-2},'electype','pad','elecori',[0.71 0.71 0;-0.71 0.71 0;0 0.71 0.71])

Run simulation on subject1 with specified recipe. Pad electrodes will be 
placed at Fp1, FC4 and POz, with default size of `[50mm 30mm 3mm]`. The long
axis will be oriented in the direction of `[0.71 0.71 0]` for the 1st pad,
`[-0.71 0.71 0]` for the 2nd pad, and `[0 0.71 0.71]` for the 3rd pad.

#### Example 14

    roast([],{'Fp1',1,'FC4',1,'POz',-2},'electype',{'pad','disc','pad'},'elecori',[0.71 0.71 0;0 0.71 0.71])

Run simulation on the MNI152 averaged head with specified recipe. A disc
electrode will be placed at FC4. Two pad electrodes will be placed at Fp1
and POz, with long axis oriented in the direction of `[0.71 0.71 0]` and 
`[0 0.71 0.71]`, respectively.

#### Example 15

    roast([],{'Fp1',1,'FC4',1,'POz',-2},'electype',{'pad','disc','pad'},'elecori',{'ap',[],[0 0.71 0.71]})

Run simulation on the MNI152 averaged head with specified recipe. A disc
electrode will be placed at FC4. Two pad electrodes will be placed at Fp1
and POz, with long axis oriented in the direction of front-back and `[0 0.71 0.71]`, respectively.

#### Example 16

    roast('example/subject1.nii',[],'T2','example/subject1_T2.nii')

Run simulation on subject1 with default recipe. The T2 image will be used 
for segmentation as well.

#### Example 17

    roast('example/subject1.nii',[],'multiaxial','on')

Run simulation on subject1 with default recipe. Segmentaion will be done by 
deep convolutional neural networks known as the Multiaxial.

#### Example 18

    roast('example/subject1.nii',[],'multiaxial','on','manualGui','on')

Run simulation on subject1 with default recipe. Segmentaion will be done by 
deep convolutional neural networks known as the Multiaxial. A 3D GUI shown below will be 
open to allow users to inspect the registration and to either confirm it or 
modify it by manually selecting the anatomical landmarks. Useful when running 
ROAST on a lesioned head for the first time to confirm if registration worked well.

manualGui

#### Example 19

    roast([],[],'meshoptions',struct('radbound',4,'maxvol',8))

Run simulation on the MNI152 averaged head with default recipe. Two of
the mesh options are customized.

#### Example 20

    roast([],[],'simulationTag','roastDemo')

Give the default run of ROAST a tag as `'roastDemo'`.

#### Example 21

    roast('example/subject1.nii',[],'resampling','on')

Run simulaiton on subject1 with default recipe, but resample the MRI of
subject1 to 1mm isotropic resolution first (the original MRI of subject1
has resolution of 1mm by 0.99mm by 0.99mm).

#### Example 22

    roast([],{'Exx19',1,'C4',-1},'zeropadding',60,'simulationTag','paddingExample')

Run simulation on the MNI152 averaged head, but add 60 empty slices on
each of the six directions to the MRI first, to allow placement of
electrode Exx19, which is outside of the MRI (i.e., several centimeters
below the most bottom slice of the MRI). This zeropadding also will generate the 
segmentation of the lower part of the head (provided `'multiaxial'` is turned off), 
thanks to the extended TPM coming along with ROAST. You can visually check this by 

    reviewRes([],'paddingExample','all')

If you run this without zero-padding first, you'll get strange results.
Note it is always a good practice to add empty slices to the MRI if you 
want to place electrodes close to, or even out of, the image boundary.
ROAST can detect if part or all of your electrode goes out of image boundary,
but sometimes it cannot tell (it's not that smart yet :-). So do a `'zeroPadding'`
of 10 to start with, and if you're not happy with the results, just increase
the amount of zero-padding. But the best solution is to get an MRI that covers
the area where you want to place the electrodes.

#### Example 23

    roast([],{'Fp1',1,'FC4',1,'POz',-2},'conductivities',struct('csf',0.6,'electrode',0.1))

Run simulation on the MNI152 averaged head with specified recipe. The
conductivity values of CSF and electrodes are customized. Conductivities
of other tissues will use the literature values.

#### Example 24

    roast([],{'Fp1',1,'FC4',1,'POz',-2},'electype',{'pad','disc','pad'},'conductivities',struct('gel',[1 0.3 1],'electrode',[0.1 5.9e7 0.1]))

Run simulation on the MNI152 averaged head with specified recipe.
Different conductivities are assigned to pad and disc electrodes. For pad
electrodes, `'gel'` is given 1 S/m and `'electrode'` is 0.1 S/m; for the disc
electrode, `'gel'` is given 0.3 S/m and `'electrode'` is 59000000 S/m. When
you control the conductivity values for each electrode individually, keep
in mind that the values you put in the vector in `'gel'` and `'electrode'`
field in `'conductivities'` option should follow the order of electrodes
you put in the `'recipe'` argument.

#### Example 25

All the options can be combined to meet your specific simulation needs.

    roast('path/to/your/subject.nii',{'Fp1',0.3,'F8',0.2,'POz',-0.4,'Nk1',0.5,'custom1',-0.6},...
        'electype',{'disc','ring','pad','ring','pad'},...
        'elecsize',{[],[7 9 3],[40 20 4],[],[]},...
        'elecori','ap','T2','path/to/your/t2.nii',...
        'meshoptions',struct('radbound',4,'maxvol',8),...
        'conductivities',struct('csf',0.6,'skin',1.0),...
        'resampling','on','zeropadding',30,...
        'simulationTag','awesomeSimulation')

Now you should know what this will do.

## 3. How to use `roast_target`

From ROAST v3.0, users can perform targeted TES (AKA optimized TES) by calling the `roast_target()` function. To be able to do targeting, you have to first run `roast()` with `leadField` as the value for argument `recipe`, i.e.,

### Example 26

    roast([],'leadField','simulationTag','MNI152leadField')

This will automatically generate all the lead field data on the MNI152 head required by `roast_target()` to perform targeting on this head. The candidate electrodes are the 74 electrodes following the 1010 system (2 electrodes on the ear are removed), and you can find their names in a separate text file under ROAST root directory (`elec72.loc`). Note generating the lead field data will usually take a lot of time (half day to a day depending on the MRI resolution and machine specs). You'll get a warning message reminding you of this, so be patient to get the lead field for targeting.

Note you can still config most of the options in ROAST even though you're generating the lead field. Options that are still usable when generating the lead field are: `T2`, `multiaxial`, `manualGui`, `meshOptions`, `simulationTag`, `resampling`, `zeroPadding`, and `conductivities`. All the options on electrodes (`capType`, `elecType`, `elecSize`, `elecOri`) cannot be used and will be set to the defaults for generating the lead field, i.e., `capType` will be set to `1010`, `elecType` will be set to `disc`, `elecSize` will be set to `[6mm 2mm]`, `elecOri` will be set to `[]`.

By default, ROAST retains the original 10-10 candidate layout for lead-field generation. Advanced workflows can instead provide a custom candidate list with `'leadFieldElectrodes'` and choose one of those candidates as the mathematical reference with `'leadFieldReference'`. Customized locations must follow the same `<subject>_customLocations` format used for ordinary simulations. This reuses the existing lead-field solver and preserves the legacy behavior when the new options are omitted.

You can also generate the lead field for the New York head, which will take even more time as the solving of the New York head (0.5 mm resolution) takes twice the time of solving a 1-mm head model.

### Example 27

    roast('nyhead','leadField','simulationTag','nyheadLeadField')

If the input MRI has 1 mm isotropic resolution, then results from using `leadField` as the recipe can be loaded into the [Soterix software HD-Explore and HD-Targets](https://soterixmedical.com/research/software). If the input MRI does not have 1 mm isotropic resolution but you turn on the `resampling` option, the generated lead field can also be readable by Soterix software.
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

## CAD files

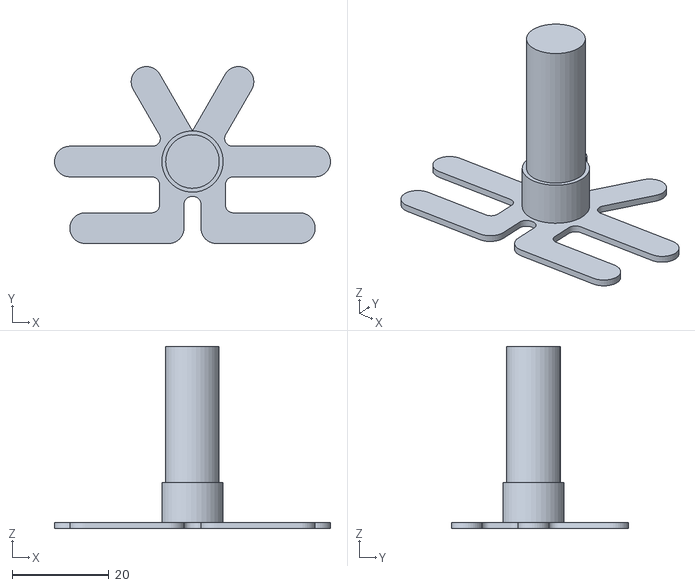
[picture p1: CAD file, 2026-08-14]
capMaker/geometry/Primate Headpost Simplified.STL
57.1 x 36.6 x 37.7

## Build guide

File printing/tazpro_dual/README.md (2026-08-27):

# TAZ Pro Dual-Extrusion Printing Helpers

This folder contains optional fabrication helpers used during NHPulse
development with a LulzBot TAZ Pro dual-extruder setup.

- `patch_tazpro_dual.py` patches Cura-style G-code for a startup wipe/home
  issue observed on one development printer.
- Future small slicer-profile or project-template files can be placed here if
  they do not contain subject-specific geometry.

See [../../docs/fabrication.md](../../docs/fabrication.md) for the tested
hardware configuration and use notes.

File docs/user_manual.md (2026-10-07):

# User Manual

NHPulse combines a transparent MATLAB workflow with a thin project application.
Most users should start with the synthetic walkthrough and then use
`nhpulseApp` to reopen manifest-backed runs and launch specialized tools.

## Core Idea

The package keeps one capMaker-compatible scalp surface as the manufacturing
geometry, uses ROAST-compatible tissue and lead-field products for electrical
modeling, and records the transformations/exclusions needed to keep implants,
ears, face regions, and printer-bed constraints consistent.

## Physical Design Mental Model

The practical object being designed is a flexible cap that sits on the dorsal
scalp. The cap is manufactured in printer-bed coordinates: the crop plane is
treated as the printer bed (`Z=0`), and cap rails/electrode holders are built
over scalp vertices above that plane. The software then keeps cap geometry away
from the cropped edge by configurable margins and applies additional local
exclusions for ears, face, implants, straps, or other regions.

A useful way to think about the early workflow is:

1. decide which part of the head can plausibly be covered by a cap,
2. remove local regions that should not receive cap material,
3. place or localize implants so the cap avoids them,
4. choose legal electrode locations on the remaining scalp,
5. model the electrical consequences of candidate locations,
6. export geometry that can actually be printed and inspected.

Future documentation should include annotated screenshots and photographs near
the beginning of the manual so users can see the intended final object before
they encounter the crop and exclusion GUIs.

## Public Tutorial Workflow

The supported public tutorial is:

```matlab
setNHPulsePath;
P = nhpulseConfigureLocalPaths('profile', 'syntheticMwe');
cfg = nhpulseExampleConfig('syntheticReviewer');
```

Then run [../exampleWalkthrough.m](../exampleWalkthrough.m) cell by cell.

## Real Subject Workflow

A real subject workflow typically replaces the synthetic inputs with:

- subject MRI or ROAST-ready NIfTI/mask products,
- model fiducials selected on the scalp/head surface,
- phone/LiDAR scan or digitizer traces for scalp/headpost localization,
- optional chamber planning and implant keepouts,
- subject-specific electrode count, target voxel, and manufacturing settings.

The high-level sequence remains:

1. Prepare anatomy and tissue labels.
2. Build or update the scalp surface.
3. Crop into printer-bed coordinates.
4. Define ear, painted, face, strap, and implant exclusions.
5. Create initial tES candidates.
6. Generate or approximate lead fields.
7. Optimize sparse tES montage.
8. Grow candidates iteratively if needed.
9. Add EEG electrodes over the remaining valid scalp.
10. Review the selected tES current recipe.
11. Inspect manufacturing geometry.
12. Export fit-check or final cap STLs.

## Interactive Steps

Several functions open MATLAB figures for user selection or refinement:

- fiducial selection,
- crop-plane selection,
- ear/painted exclusion selection,
- target voxel selection,
- headpost or chamber placement,
- Velcro attachment-loop placement.

Most of these write MAT files so a later run can reuse saved decisions. When
debugging a replay, prefer `force=false` after the first successful pass.

### Crop-Plane Selection

The crop-plane GUI asks where the printable cap footprint should end. The goal
is not to preserve the entire head mesh. For an EEG/tES cap, include the
top-level scalp that should receive cap mesh and exclude lower face/neck
regions. Later exclusions handle ears, face patches, implants, and other local
keepouts.

### Ear And Painted Exclusions

Ear exclusions keep cap rails and electrode holders away from ears. Painted
vertices mark additional local areas, such as face or eyelid regions, that
survived the crop but should not be used as electrode sites or rail endpoints.

### Implant Placement

Neurophysiology animals often have titanium headposts, chambers, or other
cranial implants. Implant placement utilities help the user represent those
objects on the head model. The resulting geometry can be used to avoid building
cap material over exposed implants and, for some workflows, to include implant
conductivity in electrical models.

### Velcro Attachment Loops

The recommended retention workflow uses external hook-and-loop straps threaded
through reinforced printed loops. `acsPlanVelcroAnchors` proposes six lateral
anchor loops: caudolateral, preauricular, and rostrolateral on each side. The
GUI opens with automatic placements and lets the user shift-click visible scalp
vertices to move the active loop. The saved MAT plan can be reused during final
STL export.

Saved anchor plans are reused only when the same output file is requested, the
source mesh fingerprint still matches, and `force=false`. To revise a saved
plan, keep the same output file and use `editMode='always'`. If the output tag
or source mesh changes, NHPulse deliberately falls back to a fresh automatic
proposal so stale anchor coordinates are not silently applied to a different
cap.

### Target Selection

The target-voxel picker selects the brain location that tES optimization should
attempt to stimulate. For real studies this target may come from MRI anatomy,
atlas coordinates, functional data, or planned recording trajectories.

## Fit-Check Before Final Manufacturing

For new subjects or newly warped scalp surfaces, a sparse PLA fit-check cap is
often faster and safer than jumping directly to a full dual-material print. The
fit-check scaffold exercises the same crop/exclusion geometry while avoiding
the longer PLA/TPE manufacturing path.

## Final Fabrication

The final manufacturing step exports coordinated TPE and PLA STL files. Slice
them as one merged dual-extrusion model so the flexible cap and rigid support
remain aligned. The tested development setup used a LulzBot TAZ Pro with PLA in
extruder 1 and NinjaTek Chinchilla TPE in extruder 2. The TPE extruder idler
tension should be loose enough that the drive gear feeds the flexible filament
without chewing it. See [3D Printing And Fabrication](fabrication.md) for
slicing, print-preparation, support-removal, and optional G-code patching notes.

To use the recommended Velcro-loop workflow, create a loop plan with
`acsPlanVelcroAnchors`, then call
`acsBuildCapMakerManufacturingStl` with `strapMode='none'`,
`velcroAnchorMode='file'`, and `velcroAnchorFile` set to the saved plan.
Printed chin straps remain available as a legacy option when explicitly
requested.

## Lead-Field Modes

The public walkthrough supports two lead-field modes:

- `dummy`: fast software check; not physically meaningful.
- `roast`: real ROAST/GetDP finite-element solve on the synthetic head.

Real experiments should use real ROAST/GetDP lead fields for final modeling and
should treat dummy lead fields only as development plumbing.

After a sparse solve, `acsShowTesStimulationParameters` can reload a saved
sparse result, combined layout, or manufacturing report and display the tES
currents to apply at each channel. When matching ROAST or EEG-prediction
products exist, the same utility can replay the corresponding field and
topography figures.

## FieldTrip EEG Topography Layouts

For preliminary EEG analysis in FieldTrip, use `acsMakeFieldTripLayout` to
convert a finalized NHPulse/capMaker layout into FieldTrip's 2-D layout
structure:

```matlab
ftLayout = acsMakeFieldTripLayout('your_cap_design_tag');

cfg = [];
cfg.layout = ftLayout.layout;
ft_topoplotER(cfg, timelock);
```

By default the adapter keeps EEG channels when they can be identified and
renames labels such as `customEEG1` to `EEG1`. Use
`'labelMode','raw'` if your FieldTrip data still uses the original NHPulse
channel names. Prefer a saved `*_report.mat` layout product or cap-design tag
over a raw ROAST `customLocations` text file because the MAT report preserves
the capMaker print-frame coordinates and EEG/tES roles.

## Data Hygiene

Do not commit real MRI data, phone/LiDAR scans, animal photographs, lead-field
results, STL/G-code products, or local path files. The `.gitignore` is set up
to keep these products out of the public repository.

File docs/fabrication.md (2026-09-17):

# 3D Printing And Fabrication

NHPulse manufacturing steps export STL files for the cap geometry, but the STL
files still need to be sliced and printed with settings appropriate for the
printer, filament, nozzles, and laboratory workflow. This page records the
configuration that has been tested during NHPulse development and gives users a
starting point for their own validation.

## Printed Parts

The final dual-material cap export produces two coordinated STL files:

- a flexible thermoplastic elastomer (TPE) cap containing the scalp rails,
  electrode holders, and either reinforced Velcro attachment loops or legacy
  printed chin straps,
- a rigid polylactic acid (PLA) support structure that stabilizes the flexible
  cap during printing and is removed after printing.

Import the two STL files into the slicer together and preserve their relative
coordinates. They should not be auto-centered independently. Assign the PLA STL
to the rigid/support-material extruder and the TPE STL to the flexible-material
extruder.

NHPulse can also export sparse PLA-only fit-check caps. These are faster,
single-material scaffolds intended to test the overall cap shape before
committing to a full dual-material print.

The currently recommended retention workflow uses reinforced Velcro attachment
loops around the cap edge instead of integrated printed chin straps.
`acsPlanVelcroAnchors` proposes six bilateral loop locations, lets the user
refine them on the scalp mesh, and saves an anchor plan. Pass that plan to the
final STL build with
`velcroAnchorMode='file'`, `velcroAnchorFile=velcroPlan.outputFile`, and
`strapMode='none'`. Printed chin straps remain available as a legacy option for
experiments that need them, but they require local validation for durability.
During final raster processing, NHPulse carves each loop's open slot through
any overlapping cap rails so the Velcro passage is clear in the exported TPE
STL. `velcroSlotClearanceMm` controls clearance around the nominal slot;
`velcroSlotCarve=false` disables this behavior for debugging or legacy output.
The loop and its thick attachment pad are also clipped against the scalp mesh
before fusion, leaving their inner surface flush with the modeled scalp while
allowing material to stand proud on the outside. This local operation tests
only candidate loop voxels and does not voxelize the full scalp. Set
`velcroScalpUndersideCarve=false` only to reproduce the earlier geometry.

## Tested Hardware

The current fabrication workflow has been tested with:

- printer: LulzBot TAZ Pro with dual-extruder tool head,
- extruder 1: 2.85 mm PLA filament with a 0.4 mm nozzle,
- extruder 2: 1.75 mm NinjaTek Chinchilla TPE filament with a 0.5 mm nozzle.

This is an example configuration, not a requirement. Other printers and
materials may work, but users should expect to validate slicer settings, bed
adhesion, support removal, holder dimensions, and cap fit locally.

## Cura Slicing Workflow

The exact Cura menu labels can vary by version, but the tested workflow is:

1. Open Cura or LulzBot Cura and select the dual-extruder TAZ Pro printer
   profile.
2. Import both STL files from the same NHPulse manufacturing run.
3. Assign the PLA/support model to extruder 1.
4. Assign the TPE/cap model to extruder 2.
5. Select both imported models and merge them so they share one coordinate
   system.
6. Center the merged model on the printer bed.
7. Load the tested NHPulse Cura settings profile, if available.
8. Slice the merged model.
9. Inspect the sliced preview layer by layer, with special attention to
   electrode-holder holes, Velcro-loop slots or legacy chin straps, implant
   keepouts, and low features near the printer bed.
10. Save the G-code to disk.
11. If using the tested TAZ Pro setup and the startup wipe/home issue applies,
    run the optional G-code patcher.
12. Keep the slicer project/profile and the final G-code with the experiment
    records.

Merge the models before centering them. Centering the PLA and TPE models
independently can destroy the alignment between the flexible cap and its
support structure.

Generated subject-specific STL and G-code files should usually remain outside
git. If you want to share printer settings with other users, prefer a small
Cura profile or project-template file and avoid committing animal-specific
geometry.

TODO: Add the tested Cura profile and Cura version after the profile has been
exported from the development workstation.

## Optional TAZ Pro G-code Patcher

The folder `printing/tazpro_dual` contains an optional Python patcher for one
TAZ Pro dual-extrusion startup problem observed during development. In that
setup, the nozzle sometimes failed to descend fully to the bed during the
startup wipe routine. The patcher writes a new `*_patched.gcode` file that:

- inserts a conservative top-of-file initialization block,
- re-homes immediately before the first `G12` wipe command,
- waits for the TPE extruder to reach print temperature before its first
  positive extrusion move.

Run it from the repository root or from any folder:

```bash
python printing/tazpro_dual/patch_tazpro_dual.py path/to/your_file.gcode
```

Keep the original G-code file and inspect the patched output in the slicer or a
G-code viewer before printing. The patcher assumes Cura-style G-code containing
a `G12` wipe command and is not a general-purpose printer repair tool.

## Print And Post-Print Checklist

Before printing:

- confirm that both extruders are assigned to the intended material,
- confirm nozzle diameters and filament diameters in the slicer,
- set the TPE extruder idler tension loose/light enough that the drive gear
  feeds the flexible filament without chewing it,
- verify that the TPE cap is not clipped by the bed or by support geometry,
- check that all electrode-holder bores remain open,
- check that Velcro loops are connected and have open slots, or that legacy
  chin straps are connected and have the expected corrugation,
- clean both nozzles so auto bed leveling can contact the bed correctly,
- apply the bed preparation used by your local protocol, such as a glue-stick
  layer for the tested TAZ Pro setup,
- prime both extruders by feeding a small amount of material,
- re-check the TPE filament after priming; if it shows bite marks or stops
  feeding, back off the idler tension and trim/re-feed the damaged segment,
- auto-home the printer before starting the job,
- keep the unpatched and patched G-code files with the print records.

After printing:

- inspect the cap before removing support material,
- remove PLA support using a locally validated process,
- follow institutional chemical-safety procedures if using alkaline PLA
  dissolution,
- test holder fit with the intended electrodes,
- perform an animal-safe fit check before experimental use.

NHPulse is research software. Printed parts are not validated medical devices,
and all animal, electrical, material, and chemical-safety procedures remain the
responsibility of the user and their institution.

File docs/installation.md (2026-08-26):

# Installation

This page is the reviewer-oriented setup path for NHPulse. It assumes MATLAB is
available and that the user has cloned the repository.

## Minimal Setup

Start MATLAB from the repository root:

```matlab
setNHPulsePath;
P = nhpulseConfigureLocalPaths('profile', 'syntheticMwe');
report = nhpulseCheckDependencies();
```

`setNHPulsePath` adds the repository folders, capMaker helpers, synthetic MWE
tools, and common bundled utility folders. `nhpulseConfigureLocalPaths` writes a
machine-local `local.paths.json` file, which is ignored by git. The dependency
report prints install links and config-field names for missing packages.

Do not run the smoke test until this report says the synthetic smoke test is
likely runnable. On a fresh machine, missing dependencies are expected.

After installing missing dependencies, rerun:

```matlab
setNHPulsePath;
P = nhpulseConfigureLocalPaths('profile', 'syntheticMwe');
report = nhpulseCheckDependencies();
```

Then run:

```matlab
smokeOut = nhpulseRunSyntheticSmokeTest('force', true, 'showFigures', true);
```

If you want folder and executable pickers:

```matlab
P = nhpulseConfigureLocalPaths('profile', 'syntheticMwe', 'useGui', true);
```

## Expected Local Folders

Generated products should live outside version control, normally under
`outputs/`. Real MRI data, phone/LiDAR scans, animal photos, and printer outputs
should stay in private folders or in a configured external data root.

The repository includes an empty `lib/` folder as a convenience place to unpack
local dependencies. Dependencies placed there are ignored by git. Exact folder
names are not required for common MATLAB libraries: `setNHPulsePath` searches
under `lib/` for diagnostic files such as `spm_vol.m`, `vol2mesh.m`, and
`cvx_setup.m`. For example, an SPM download named `spm12-main` can remain at
`lib/spm12-main`.

The generated `local.paths.json` may contain:

- `outputRoot`: generated synthetic examples, QC figures, lead fields, and STL
  products.
- `dataRoot`: private source data for real subjects.
- `roastWorkRoot`: scratch space for ROAST products.
- `spmPath`, `iso2meshPath`, `cvxPath`: optional external MATLAB libraries.
- `getdpExecutable`, `gmshExecutable`: solver/mesh executables for real ROAST
  lead-field runs.

You can set these values in either of two ways:

```matlab
P = nhpulseConfigureLocalPaths('profile', 'syntheticMwe', 'useGui', true);
```

or edit `local.paths.json` directly after it is created. Use full paths for
folders and executable files.

## Dependencies

The synthetic smoke test requires MATLAB, NHPulse's bundled simple NIfTI
reader/writer, Image Processing Toolbox, and Statistics and Machine Learning
Toolbox. It is designed to run even when SPM's compiled NIfTI MEX files are
not working on a fresh Apple Silicon install. Real ROAST/SPM segmentation and
real lead-field generation still require a working SPM install; full
lead-field generation additionally requires iso2mesh/TetGen, GetDP, and often
Gmsh. Sparse optimization with CVX is optional for the public synthetic
walkthrough because the tutorial can use a development heuristic.

See [../DEPENDENCIES.md](../DEPENDENCIES.md) for install links and third-party
notices.

## macOS Quarantine

Downloaded MATLAB dependencies on macOS may contain quarantined MEX files or
non-executable helper binaries. After configuring paths, run:

```matlab
nhpulseClearMacQuarantine({'spm', 'cvx', 'iso2mesh', 'getdp'})
```

You can also pass a folder path directly. Restart MATLAB afterward. GetDP is
only needed for real ROAST finite-element solves, but it can be quarantined by
macOS in the same way as MEX dependencies.

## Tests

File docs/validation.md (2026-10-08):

# Validation

NHPulse currently combines lightweight automated checks with documented manual
reviewer tests. The manual pieces are intentional because several workflow
steps involve MATLAB figure GUIs and STL inspection.

## Dependency Report

```matlab
setNHPulsePath;
report = nhpulseCheckDependencies();
```

This reports obvious missing MATLAB products, functions, and external solver
paths.

## Smoke Test

```matlab
smokeOut = nhpulseRunSyntheticSmokeTest('force', true, 'showFigures', true);
```

The smoke test creates synthetic anatomy, builds a scalp cache, and places a
small custom cap layout. It intentionally stops before long ROAST/GetDP solves.

## Full Synthetic Walkthrough Verification

After running `exampleWalkthrough.m`:

```matlab
verification = nhpulseVerifySyntheticWalkthrough();
```

The verifier checks expected product classes:

- synthetic T1 and hard-label mask,
- scalp and printer-bed mesh caches,
- ear/painted exclusions,
- headpost placement and keepout,
- target voxel selection,
- fit-check STL,
- tES candidate and tES+EEG layout reports,
- Velcro anchor plan,
- final TPE/PLA manufacturing STLs,
- optional real ROAST lead-field result.

## Provenance Self-Tests

```matlab
nhpulseTestManifestRecorder;
nhpulseTestProjectInspection;
nhpulseTestServiceLayer;
nhpulseTestApplicationShell;
```

These fast tests use temporary files only. They verify manifest round trips,
fingerprints, stale dependency propagation, artifact hierarchy checks, project
opening, read-only legacy discovery, and dry-run import behavior.
The service-layer test additionally checks explicit context resolution,
workspace independence, stale-input rejection, and dependency refresh.
The application-shell test opens a hidden project window and verifies project,
subject, run, workflow, and artifact-table population. It also verifies legacy
artifact display and explicit import into a subject-labeled inventory run.

## Manual Checks

For a reviewer-oriented run, inspect:

- crop-plane QC figure,
- ear/painted exclusion GUI or saved exclusion report,
- headpost placement/keepout QC,
- tES growth and EEG layout QC figures,
- Velcro anchor placement QC,
- final manufacturing QC figure,
- exported STL files in slicer or mesh-viewer software.

## Future Test Targets

Planned public-development milestones include small unit tests for config
helpers, file-format generators, mesh-cache fingerprints, exclusion reuse, and
deeper geometry assertions for manufacturing products.

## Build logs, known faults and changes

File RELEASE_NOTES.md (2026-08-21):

# Release Notes

## v0.1.0-alpha

First public alpha release of NHPulse.

Highlights:

- Bundled a modified ROAST/capMaker research workflow for NHP EEG/tES cap
  design.
- Added synthetic ROAST-ready data generation for public testing.
- Added a documented end-to-end `exampleWalkthrough.m` that reaches fit-check
  and dual-material STL export.
- Added setup helpers for MATLAB path configuration and machine-local paths.
- Added dependency reporting and macOS quarantine helper utilities.
- Added support for optional real ROAST/GetDP lead-field solves on the
  synthetic walkthrough.

Known limitations:

- The public workflow is still script/cell based rather than a comprehensive
  GUI.
- Full real-subject workflows remain active research code and require careful
  QC at each step.
- Automated tests are limited; the synthetic walkthrough plus verification
  helper are the current reviewer-facing validation path.

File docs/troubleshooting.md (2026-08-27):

# Troubleshooting

This page records failures seen during fresh-clone testing and the shortest
known path to diagnose them.

## Read-Only Output Folder

If MATLAB reports a read-only file system while creating synthetic outputs,
choose a writable `outputRoot`:

```matlab
P = nhpulseConfigureLocalPaths('profile', 'syntheticMwe', 'useGui', true);
```

Pick a folder under your home directory.

## Missing SPM Or NIfTI Functions

The public synthetic smoke test uses NHPulse's bundled simple NIfTI reader and
writer for its generated toy files. Full real-subject workflows still use SPM
heavily. Errors involving `spm_vol`, `spm_preproc_run`, or SPM segmentation
usually mean SPM is not on the MATLAB path. Install SPM and configure:

```matlab
P = nhpulseConfigureLocalPaths('profile', 'syntheticMwe', 'useGui', true);
report = nhpulseCheckDependencies();
```

NHPulse includes `load_untouch_nii` and `save_untouch_nii` compatibility
wrappers that prefer SPM but can fall back to bundled simple NIfTI I/O for the
synthetic/demo files. A separate legacy NIfTI toolbox is normally not needed.

## SPM MEX Files Are Not Compiled On Apple Silicon

On Apple Silicon Macs, source-only or platform-mismatched SPM downloads may
show warnings such as:

```text
spm_existfile is not compiled for your platform
mat2file.c not compiled - see Makefile
spm_slice_vol.c was not compiled
```

This means MATLAB can see SPM functions, but at least one compiled SPM
NIfTI/resampling helper is unavailable for the current platform. NHPulse's
synthetic smoke-test path can fall back to `nhpulseReadSimpleNifti` and
`nhpulseWriteSimpleNifti` for the generated toy files. However, full SPM
segmentation and upstream ROAST/SPM paths still require a working,
platform-compatible SPM install.

First confirm that you downloaded the current SPM release from the main SPM
download page rather than an older source snapshot. If the right `.mexmaca64`
files are present but macOS blocks them, clear quarantine:

```matlab
nhpulseClearMacQuarantine('spm')
```

or pass the exact folder:

```matlab
nhpulseClearMacQuarantine('/Users/you/Documents/MATLAB/NHPulse/lib/spm12-main')
```

Restart MATLAB afterward.

To diagnose:

```matlab
setNHPulsePath;
report = nhpulseCheckDependencies();
report.spm
```

## macOS Blocks MEX Files

Symptoms include "Invalid MEX-file", "developer cannot be verified", "library
load disallowed by system policy", or `Permission denied` from `cgalmesh` or
GetDP.

After configuring dependency paths:

```matlab
nhpulseClearMacQuarantine({'spm', 'cvx', 'iso2mesh', 'getdp'})
```

Restart MATLAB. For CVX, rerun `cvx_setup`.

If `nhpulseClearMacQuarantine('getdp')` says the GetDP path is not found or
not configured, rerun local path setup after installing GetDP:

```matlab
P = nhpulseConfigureLocalPaths('profile', 'syntheticMwe', 'useGui', true);
```

or pass the folder/executable directly, for example:

```matlab
nhpulseClearMacQuarantine('/Users/you/Documents/MATLAB/NHPulse/lib/getdp-3.2.0')
```

## Gmsh App Bundle On macOS

If you downloaded `Gmsh.app`, the command-line executable is inside the bundle:

```text
Gmsh.app/Contents/MacOS/gmsh
```

`nhpulseConfigureLocalPaths` and `nhpulseCheckDependencies` try to resolve this
automatically if you select the `.app` folder.

## GetDP Not Found

The full ROAST lead-field path needs a GetDP executable. Configure it with the
GUI or edit `local.paths.json`:

```matlab
P = nhpulseConfigureLocalPaths('profile', 'syntheticMwe', 'useGui', true);
report = nhpulseCheckDependencies();
```

## TAZ Pro Startup Wipe Or Bed-Leveling Problems

If a LulzBot TAZ Pro dual-extrusion print starts with the nozzle too high or
too low during wiping or bed leveling, first check physical setup: both nozzles
should be clean, both extruders should be primed, and the printer should be
auto-homed before the job.

For one tested TAZ Pro setup, NHPulse includes an optional Cura-style G-code
patcher that re-homes before the first `G12` wipe command and waits for the TPE
extruder before its first extrusion:

```bash
python printing/tazpro_dual/patch_tazpro_dual.py path/to/your_file.gcode
```

This writes `*_patched.gcode` next to the input file. Keep the original G-code
and inspect the patched file before printing. See
[3D Printing And Fabrication](fabrication.md) for the full slicing checklist.

## ROAST Custom Segmentation Or capInfo Errors

The synthetic walkthrough supplies a custom hard-label mask so ROAST can skip
SPM segmentation. It also uses custom electrode locations, so upstream
`capInfo.xlsx` should not be required for the public synthetic path. If ROAST
tries to segment or asks for `capInfo.xlsx`, make sure you are running the
current repository version and restart MATLAB with:

```matlab
clear functions;
setNHPulsePath;
```

## Gel Labels Missing In The Synthetic ROAST Path

The synthetic ROAST path uses a stacked disc electrode/gel model that is sized
for the toy mesh. Use:

```matlab
cfg = nhpulseExampleConfig('syntheticRoast');
```

If you override electrode geometry, inspect domains with:

```matlab
nhpulseInspectRoastLeadFieldDomains(syntheticOut.t1File, simulationTag)
```

## Verification Fails

Run:

```matlab
verification = nhpulseVerifySyntheticWalkthrough();
```

The printed table names the missing product class. If only the real lead-field
check is missing, confirm whether you used the default dummy mode. Dummy mode is
expected to skip real ROAST result files.

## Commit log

2026-08-14 Prepare public synthetic walkthrough and dependency cleanup
    Add a synthetic MWE generator and smoke-test walkthrough for reviewer-friendly installation checks.
    Rewrite exampleWalkthrough.m into a compact synthetic-first tutorial.
    Replace third-party notes with broader dependency documentation and a lightweight dependency checker.
    Remove the live Polhemus/FasTrak acquisition interface.
    Clarify that real MRI, phone/LiDAR scans, photographs, and generated outputs should stay outside git.
    Add raw scan export patterns to .gitignore.
2026-08-20 Roast OS compatability fixes
    Changed:
    [roast.m]: added a showFigures option and wrapped ROAST’s internal MRI/segmentation/electrode/result viewers.
    [acsGenerateRoastLeadField.m]: now defaults ROAST lead-field solves to showFigures=false.
    [exampleWalkthrough.m]: added cfg.realLeadFieldShowFigures = false.
    [sliceshow.m], [solveByGetDP.m], [runNiftyReg.m], [runMultiaxial.m]: Apple Silicon maca64 now follows the existing macOS branch.
2026-08-21 Make demo electrodes larger for roast solve
2026-08-21 roast demo electrode meshing improvements and diagnostics
2026-08-21 More electrode/gel meshing fixes
2026-08-21 Even more gel/electrode meshing fixes
2026-08-27 Automatically increase chin strap ramp to meet main cap if needed
2026-09-04 Starting new velcro strap attachment loops
2026-09-17 First steps to add project manifest management
    The new API includes:
    - nhpulseCreateManifest
    - nhpulseRegisterArtifact
    - nhpulseArtifactRef
    - nhpulseSaveManifest
    - nhpulseLoadManifest
    - nhpulseCheckManifest
    The recorder provides:
    - Relative paths for movable output trees
    - Automatic project-root relocation after moving a tree
    - Explicit parent roles and fingerprints
    - Stale-state propagation through the dependency graph
    - Missing-file, duplicate-ID, unresolved-parent, and cycle detection
    - MAT and JSON manifests
    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
2026-10-06 Started wiring manifests into major pipeline stages
2026-10-07 Add manifest-backed pipeline service layer
    Introduce explicit project contexts and registered artifact handles for major
    NHPulse pipeline stages, removing reliance on populated MATLAB workspaces.
    Add stable services for scalp preparation, cropping, exclusions, fiducials,
    target selection, implant placement, fit checks, layout construction and
    growth, lead-field generation, montage optimization, retention planning, and
    manufacturing. Validate artifact types, dependency freshness, and provenance
    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
2026-10-09 bug fix
    The app’s workflow-status code mixed an N×1 logical mask with a 1×N comparison
2026-10-15 utilities for simple test print objects

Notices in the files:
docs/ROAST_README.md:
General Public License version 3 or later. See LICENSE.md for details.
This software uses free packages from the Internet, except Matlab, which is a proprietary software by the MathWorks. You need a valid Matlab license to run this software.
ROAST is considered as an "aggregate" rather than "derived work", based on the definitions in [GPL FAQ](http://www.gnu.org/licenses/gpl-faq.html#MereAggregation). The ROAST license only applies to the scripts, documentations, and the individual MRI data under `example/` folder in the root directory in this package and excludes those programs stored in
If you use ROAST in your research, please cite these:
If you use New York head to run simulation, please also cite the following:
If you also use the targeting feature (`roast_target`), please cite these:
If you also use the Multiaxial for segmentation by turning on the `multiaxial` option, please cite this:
